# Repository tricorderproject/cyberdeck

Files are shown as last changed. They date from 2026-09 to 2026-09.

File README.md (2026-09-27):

# Open Source Science Tricorder Cyberdeck

Explore alien planets with... the open source science tricorder cyberdeck!

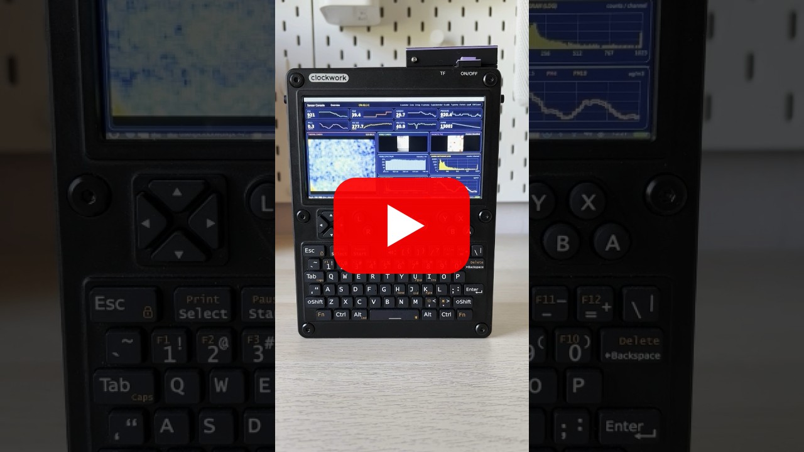
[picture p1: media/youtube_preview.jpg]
Watch the Open Source Science Tricorder Cyberdeck on YouTube


# What is this

This is the Github Repository for the **Open Source Science Tricorder Cyberdeck**, an open-source hardware tricorder-like device similar in function to some of the science tricorder devices from the science fiction series Star Trek.  These devices essentially pack a large number of scientific sensors into small hand-held devices, with the (science fiction) intent being that they would be broadly useful for exploring alien worlds, and making new scientific discoveries.

# Table of Contents

- [What is this](#what-is-this)
- [Pictures](#pictures)
- [Frequently Asked Questions](#frequently-asked-questions)
- [Sensor/Hardware List](#sensorhardware-list)
  - [UConsole](#uconsole)
  - [Main Sensors](#main-sensors)
- [Custom PCBs](#custom-pcbs)
  - [PCB: Hamamatsu Microspectrometer Breakout](#pcb-hamamatsu-microspectrometer-breakout)
  - [PCB: ESP32 Breakout](#pcb-esp32-breakout)
  - [PCB: USB Hub Breakout](#pcb-usb-hub-breakout)
- [3D Printed Components](#3d-printed-components)
  - [3D Print: Main Body](#3d-print-main-body)
  - [3D Print: Back Plate](#3d-print-back-plate)
  - [3D Print: Magnetometer Top and Bottom](#3d-print-magnetometer-top-and-bottom)
  - [3D Print: Power Switch](#3d-print-power-switch)
- [Physical Assembly Video](#physical-assembly-video)
- [Firmware (ESP32)](#firmware-esp32)
- [User Interface (Python/UConsole)](#user-interface-pythonuconsole)
- [Design Philosophy and Iterations](#design-philosophy-and-iterations)
  - [Where it was coming from: The Arducorder Mini](#where-it-was-coming-from-the-arducorder-mini)
  - [Iteration 8: Attaching something to an iPhone](#iteration-8-attaching-something-to-an-iphone)
  - [Iteration 9: Teensycorder: Trying to make something that looked like a BlackBerry](#iteration-9-teensycorder-trying-to-make-something-that-looked-like-a-blackberry)
  - [Iteration 10: T-Deck-Corder](#iteration-10-t-deck-corder)
  - [Iteration 11: Initial Cyberdeck explorations with the BTree](#iteration-11-initial-cyberdeck-explorations-with-the-btree)
  - [Iteration 12: A smaller Cyberdeck with the Clockwork Pi PicoCalc](#iteration-12-a-smaller-cyberdeck-with-the-clockwork-pi-picocalc)
  - [Iteration 13: The Open Source Science Tricoder Cyberdeck](#iteration-13-the-open-source-science-tricoder-cyberdeck)
- [Errata](#errata)
  - [Things that are real errors](#things-that-are-real-errors)
  - [Things that I just don't like, or that aren't implemented yet](#things-that-i-just-dont-like-or-that-arent-implemented-yet)
- [AI Usage](#ai-usage)
- [License](#license)
- [Warranty](#warranty)
- [Contact](#contact)

# Pictures

| Main Screen | Spectrometer Screen | Magnetic imager in use (1) | Magnetic imager in use (2) |
| :---: | :---: | :---: | :---: |
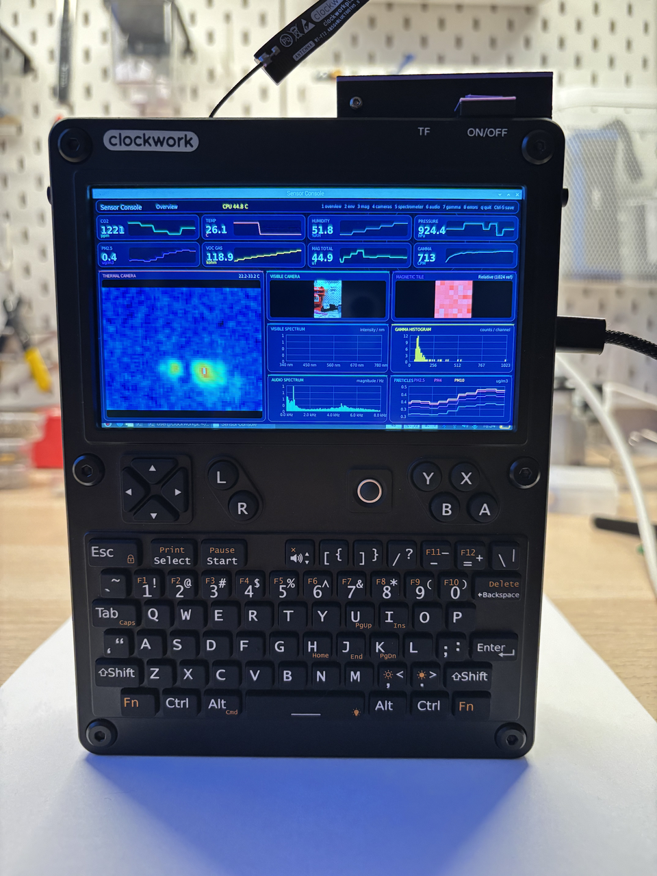
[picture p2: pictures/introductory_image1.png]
Introductory image 1
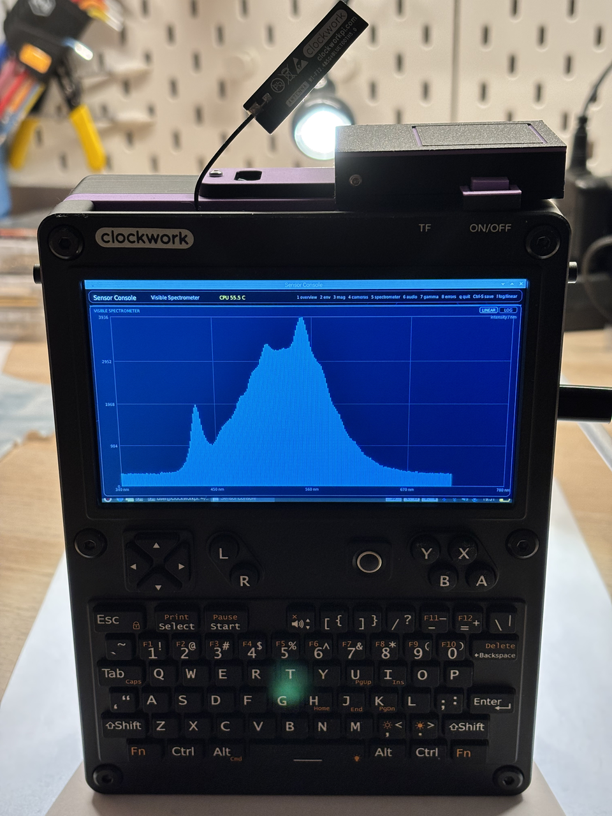
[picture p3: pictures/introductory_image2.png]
Introductory image 2
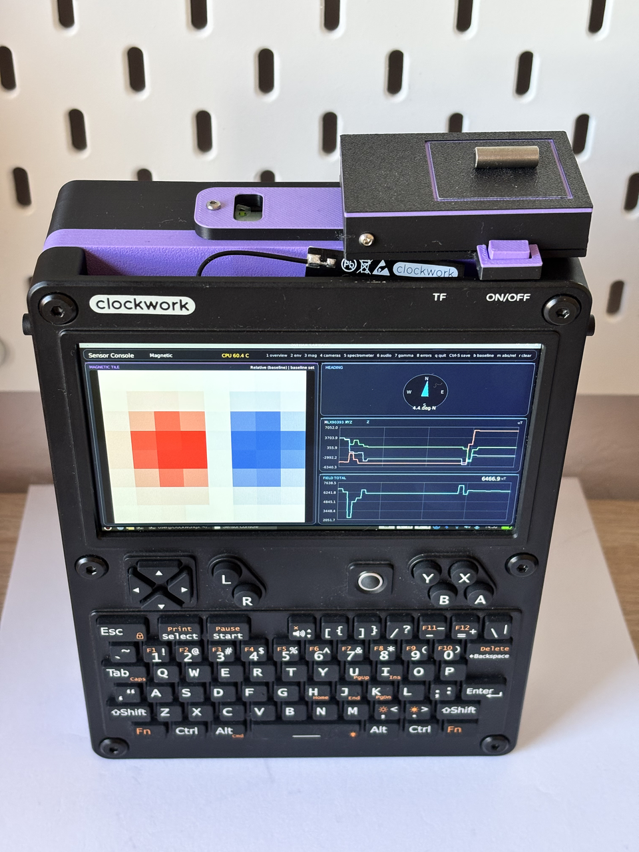
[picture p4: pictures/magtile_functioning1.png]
Magnetic imaging tile in use
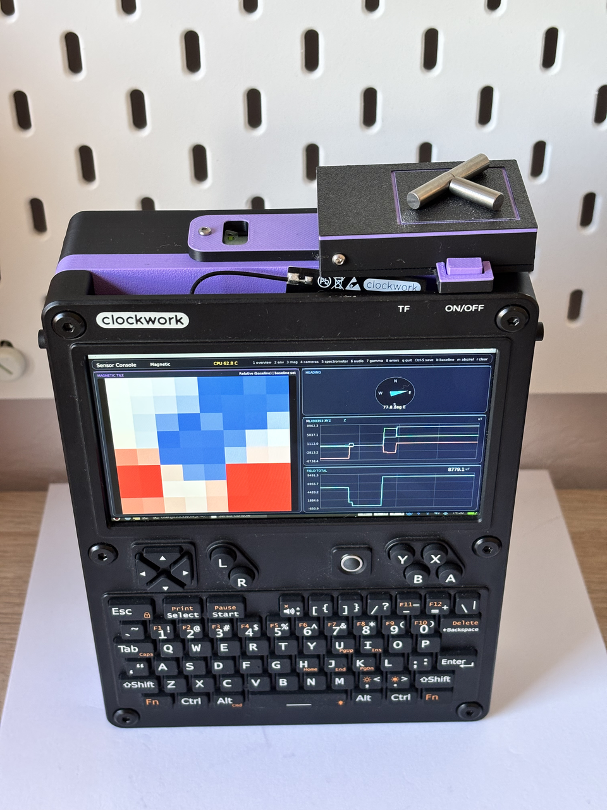
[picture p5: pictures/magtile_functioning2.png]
Magnetic imaging tile in use
|  |  |  |  |
| **Main body with components** | **Main body and back cover** | **Assembled (from back)** | |
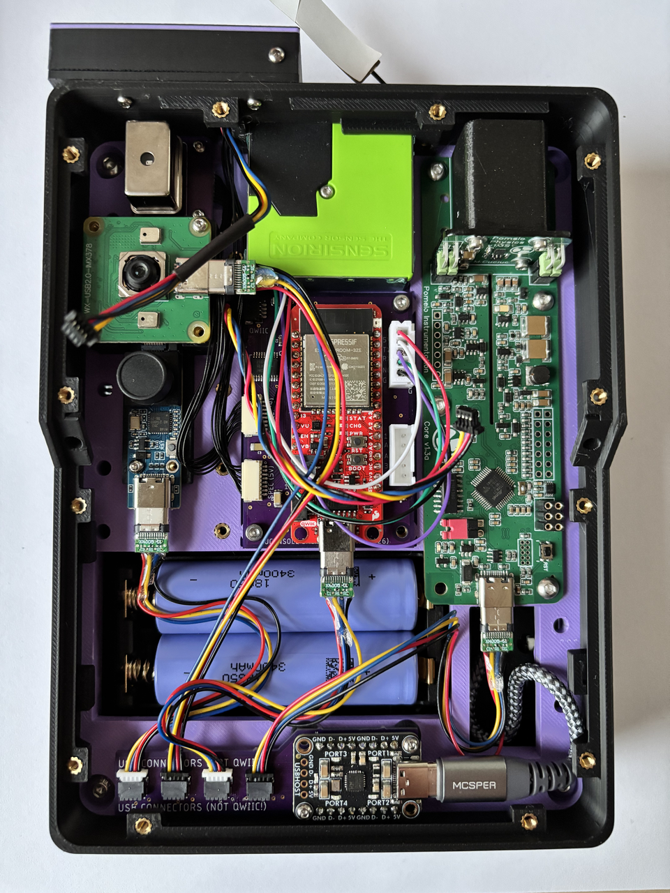
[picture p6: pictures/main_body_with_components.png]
Main body with components installed
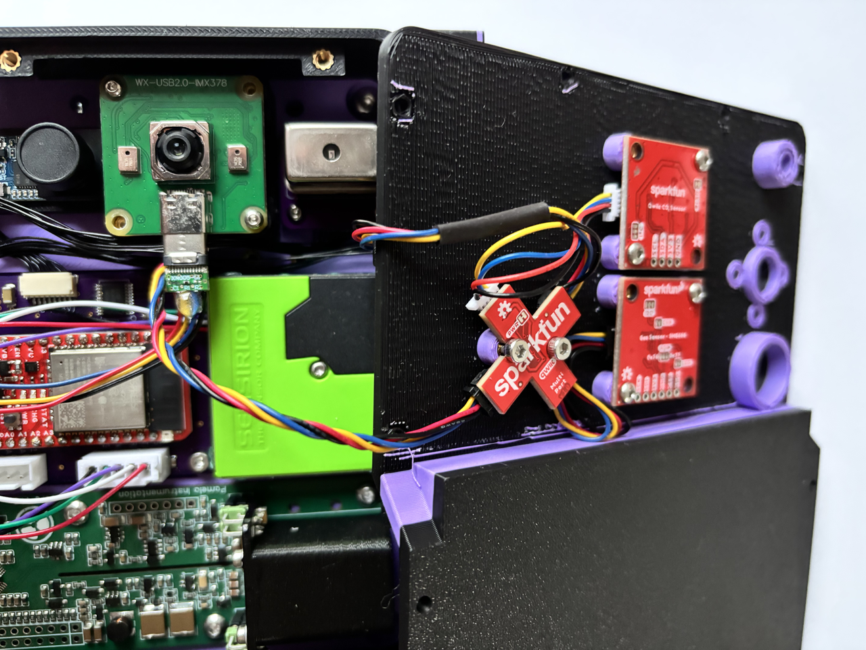
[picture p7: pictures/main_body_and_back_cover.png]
Main body and back cover, opened
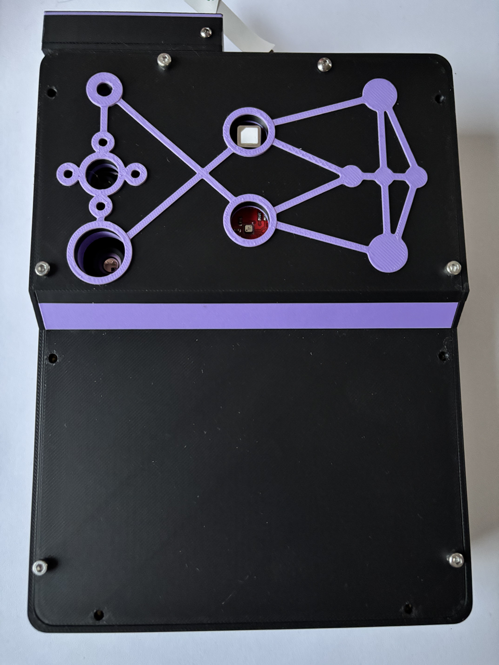
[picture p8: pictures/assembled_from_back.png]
Assembled, viewed from the back
|  |  |  | |

# Frequently Asked Questions

**Q1: What is a tricorder?**

A tricorder is a fictional device from the TV series Star Trek, that characters (like Spock) would take with them when they traveled to alien planets.  The tricorder is essentially like a box full of sensors, that would tell them all sorts of things about the environments they would travel to -- like detecting lifeforms, helping them make discoveries, or solve whatever challenges they faced.  There are nominally two kinds of tricorders in the shows -- medical tricorders (that they use for medical diagnosis), and the science tricorders, which they use for scientific/exploratory tasks. 

**Q2. What can it sense?**

This currently has the following sensing capabilities:
- **Thermal Imaging:** a 80x62 Waveshare imager, paired with a regular visible USB camera
- **Visible Spectroscopy:** a Hamamatsu C12666MA microspectrometer, with 256 spectral channels between 340nm and 780nm (in practice, the spectral resolution is about 15nm)
- **Magnetic Field Imager:** An 8x8 (64 pixel) magnetic field camera, provided by the Sparkfun Magnetic Imaging Tile. In practice this can go up to about 20KHz (i.e. 20,000 frames per second). This is also paired with a regular magnetometer (MLX90393) for magnetic field strength and direction.
- **Radiation Spectroscopy:** Where previous open source science tricorders have included radiation sensors, this version includes the Pomelo radiation spectroscopy detector, which uses a scintillation crystal and can differentiate energy levels.
- **Environmental Sensors:** CO2 level, VOC level, Air particulate matter (e.g. PM1/2.5/4/10), ambient temperature, pressure, and humidity.

**Q3: What is a cyberdeck?**

A cyberdeck is the name for essentially small handheld consoles (that include small screens and keyboards), that frequently run full operating systems, and that are often designed to be hackable/modified.  This build is based on the [UConsole by Clockwork Pi](https://www.clockworkpi.com/home-uconsole), which uses a Raspberry Pi compute module -- so it runs linux, and has several cores, about 4GB of RAM, and lots of eMMC storage. 

**Q4: Are there videos showing it functioning?**

Yes, [here is a video on Youtube](https://youtube.com/shorts/MCvRtOt6pII) showing its main functionality. 

**Q5: Is there a video of it being assembled/the inside?**

Yes!  [Here is a video of the inside being put together](https://youtube.com/shorts/LsJ3JqqFUqU), component by component.

**Q6: What does open source mean in the context of open hardware?**

Open hardware is like open source software, except that it is the designs for the device that are openly shared/distributed.  The software/firmware for the device is also included. 

**Q7: Can I build this?**

The honest answer is -- maybe.  This is a prototype, not a product, and there are lots of rough edges.  Historically, most of the utility from the past releases of the open source science tricorders seems to be educational, inspirational (i.e. a real tricorder-like device!), or derivatives (e.g. folks using part of the designs for their own work).  The devices are quite complex to build, and quite expensive.  

**Q8: Why did you build this?**

I grew up watching Star Trek, and my first career choice was always space explorer -- it just turned out that I was born a little early for that to be a common occupation.  But we're not going to get there just sitting around -- we make the future ourselves, so let's build the technology to become future explorers, and make new discoveries together.

**Q9: Who was this made by?**

The Open Source Science Tricorder Project is an open-source educational outreach by Dr. Peter Jansen, a professor at the University of Arizona.  You can learn more about me [here](https://cognitiveai.org/).

**Q10: How many past open source science tricoders have their been?**

I have made about a dozen designs, but only four (including this cyberdeck) have been official 'releases' with significant documentation, the others are generally iterations or prototypes (and some of the failed prototypes for this cyberdeck design are shown in the section below, since it's always exciting to see the development process!). I used to post a design blog on the process, but I am a little busy these days, and don't have a lot of free time, so it now takes me longer to build these things than I am willing to admit. 

The past major releases are the [Mark 1](https://tricorderproject.org/tricorder-mark1.html) and [Mark2 2](https://tricorderproject.org/tricorder-mark2.html) in 2012, the [Arducorder Mini](https://hackaday.io/project/1395-open-source-science-tricorder) in 2014, and then this Cyberdeck in 2026.  In the interim, I also worked on other educational open source hardware projects, like the open source computed tomography (CT) scanners. 

**Q11: How much did this Cyberdeck cost to build?**

The UConsole itself, CM4 compute module, and associated HackerGadgets extension boards, are likely around $300-$400, while the components and build here are likely around $1000.  The visible microspectrometer and the pomelo radiation spectrometer are by far the most expensive components.

# Sensor/Hardware List

The following is the core hardware used in this device, including links to datasheets/etc.

## UConsole

| Component | Description | Link |
| --- | --- | --- |
| UConsole | Clockwork Pi UConsole | [ClockworkPi](https://www.clockworkpi.com/home-uconsole) |
| UConsole Extension | Internal USB Hub, CM5 adapter, battery board | [Hacker Gadgets](https://hackergadgets.com/products/uconsole-upgrade-kit) |

## Main Sensors

| Component | Description | Link |
| --- | --- | --- |
| Thermal Camera | Waveshare Long-wave IR Camera (80x62, USB C) | [Waveshare](https://www.waveshare.com/thermal-camera.htm?sku=25288) |
| USB Camera | Waveshare IMX378 12MP | [Waveshare](https://www.waveshare.com/imx378-12mp-usb-camera-a.htm) |
| Microspectrometer | Hamamatsu C12666MA | [Hamamatsu](https://www.hamamatsu.com/us/en/product/optical-sensors/spectrometers/mini-spectrometer/C12666MA.html) |
| Radiation Sensor | Pomelo Spectroscopic Radiation Detector | [Crowd Supply](https://www.crowdsupply.com/pomelo-instrumentation/pomelo) |
| Air Particle Sensor | Sensirion Particulate Matter Sensor SPS30 | [Sensirion](https://sensirion.com/products/catalog/SPS30) |
| Magnetic Imaging Tile | SparkFun Magnetic Imaging Tile - 8x8 | [SparkFun](https://www.sparkfun.com/sparkfun-magnetic-imaging-tile-8x8.html) |
| Magnetometer | MLX90393 Breakout | [SparkFun](https://www.sparkfun.com/sparkfun-triple-axis-magnetometer-breakout-mlx90393-qwiic.html) |
| CO2 Sensor | SCD40 CO2/Temp/Humidity Breakout | [SparkFun](https://www.sparkfun.com/sparkfun-co2-humidity-and-temperature-sensor-scd40-qwiic.html) |
| Environmental Sensor | BME680 Temp/Pressure/Humidity/VOC | [SparkFun](https://www.sparkfun.com/sparkfun-environmental-sensor-breakout-bme680-qwiic.html) |
| QWIIC Hub | SparkFun Qwiic MultiPort | [SparkFun](https://www.sparkfun.com/sparkfun-qwiic-multiport.html) |

In addition to the hardware above, a handful of custom PCBs are used (described below).

# Custom PCBs

While effort was made to try and have everything in the device be off-the-shelf for this build, a handful of boards were used to make things a little more compact. 

## PCB: Hamamatsu Microspectrometer Breakout

This is a small breakout for the Hamamatsu CD12666MA microspectrometer, that primarily provides a low-profile connector, an op-amp buffer, and handful of filtering passives to help keep the power clean. 

| Board (front) | Board (back) | PCB (top) | PCB (bottom) |
| :---: | :---: | :---: | :---: |
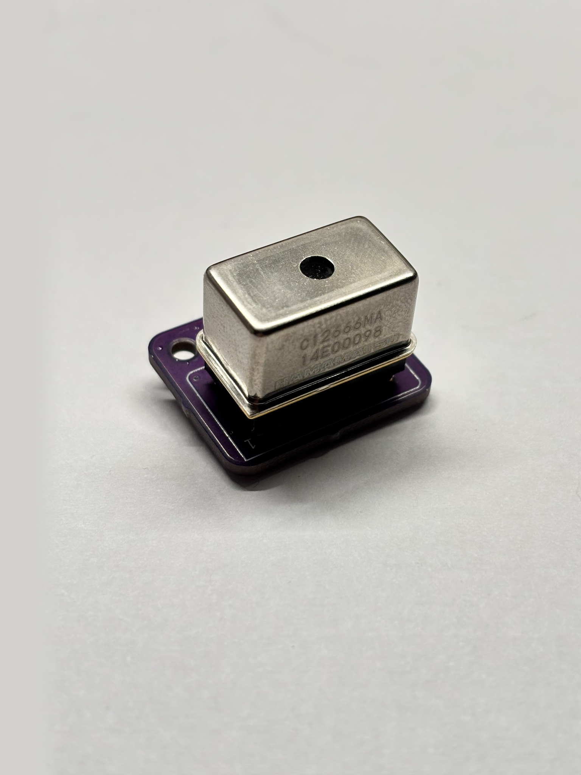
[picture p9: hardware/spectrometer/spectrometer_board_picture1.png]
Spectrometer breakout, front
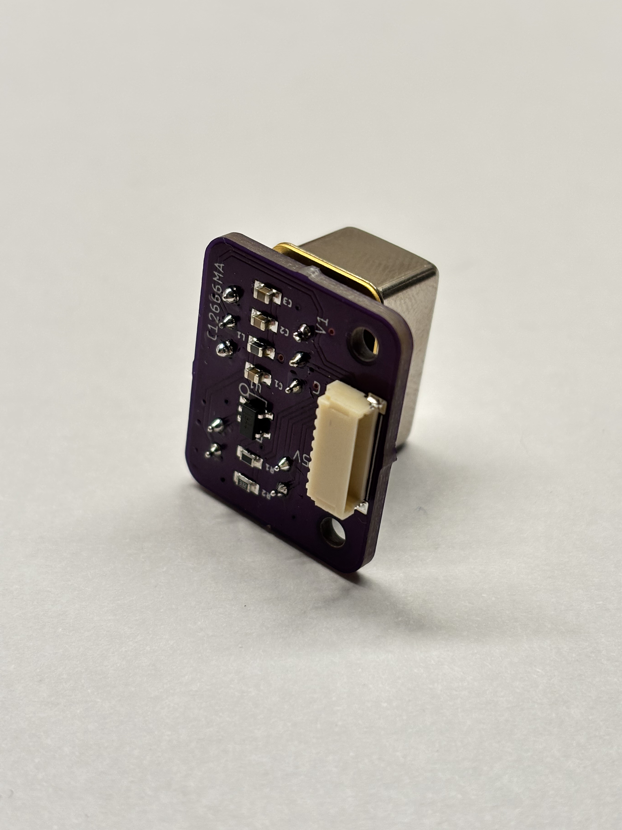
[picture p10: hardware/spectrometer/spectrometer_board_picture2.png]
Spectrometer breakout, back
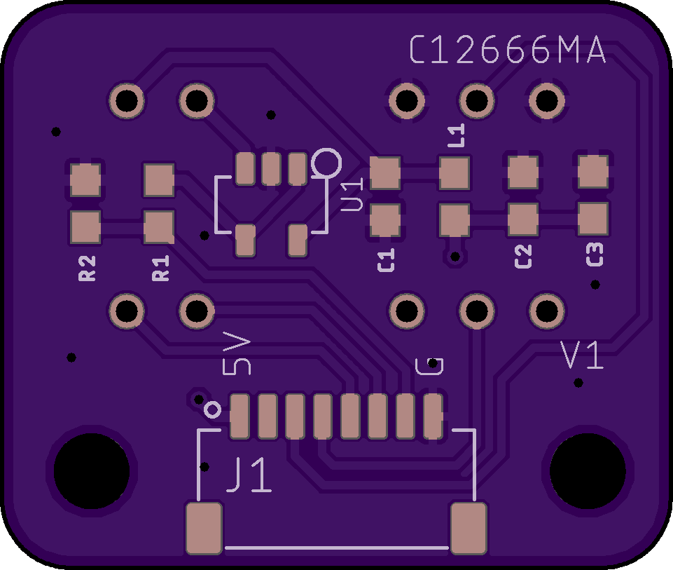
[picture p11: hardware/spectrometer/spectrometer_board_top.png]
Spectrometer breakout PCB render, top
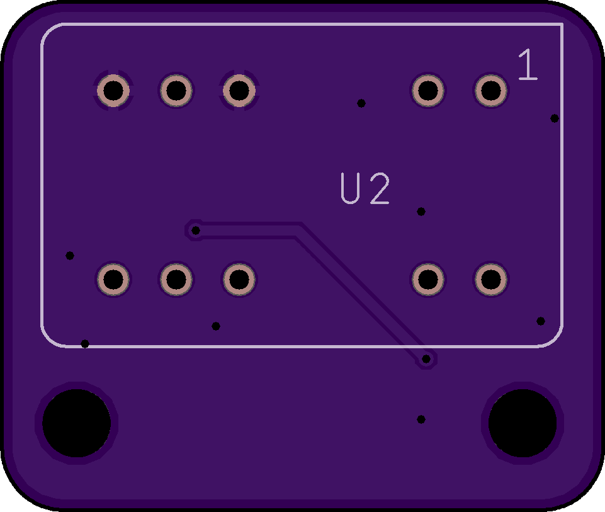
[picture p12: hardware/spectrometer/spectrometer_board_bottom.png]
Spectrometer breakout PCB render, bottom
|  |  |  |  |
| **Reflow (toaster oven)** | | | |
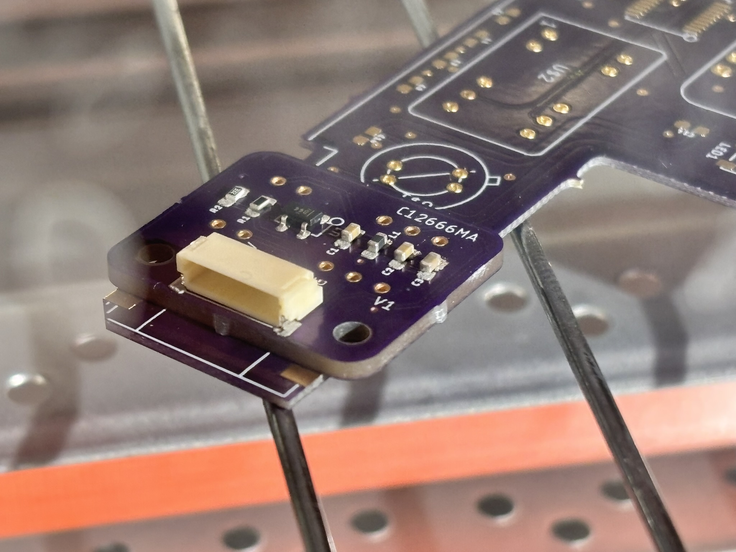
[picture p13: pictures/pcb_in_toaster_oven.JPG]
Spectrometer breakout PCB being reflowed in a toaster oven
|  | | | |

**Design files (EAGLE 9.6.2):** [Schematic (PDF)](hardware/spectrometer/spectrometer-breakout-1c2.pdf) &middot; [Schematic (.sch)](hardware/spectrometer/spectrometer-breakout-1c2.sch) &middot; [Board (.brd)](hardware/spectrometer/spectrometer-breakout-1c2.brd) &middot; [Parts list](hardware/spectrometer/spectrometer-breakout-1b2-partslist.txt)

## PCB: ESP32 Breakout

This is an ESP32 breakout that provides a handy connection between the UConsole (over USB) to most of the other (non-USB) sensors.  The ESP32 board itself is the [Sparkfun ESP32-WROOM USB C](https://www.sparkfun.com/sparkfun-thing-plus-esp32-wroom-usb-c.html). On the left there are small-form connectors for the spectrometer, magnetic imaging tile, and a QWIIC I2C connector.  On the right side are two standard 0.1-spaced headers, one for communicating with the SPS30 air particle sensor, and the other is open, and is intended for a light source for the visible spectrometer. 

| Board | PCB (top) | PCB (bottom) |
| :---: | :---: | :---: |
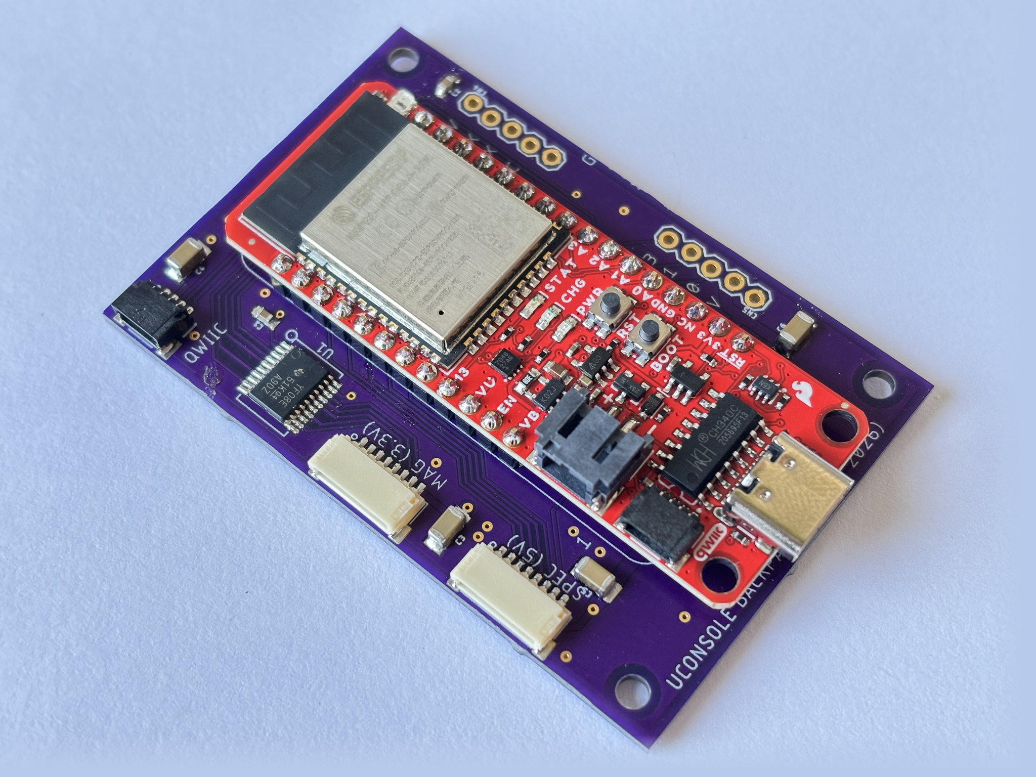
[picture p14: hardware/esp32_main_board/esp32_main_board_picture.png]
ESP32 breakout board
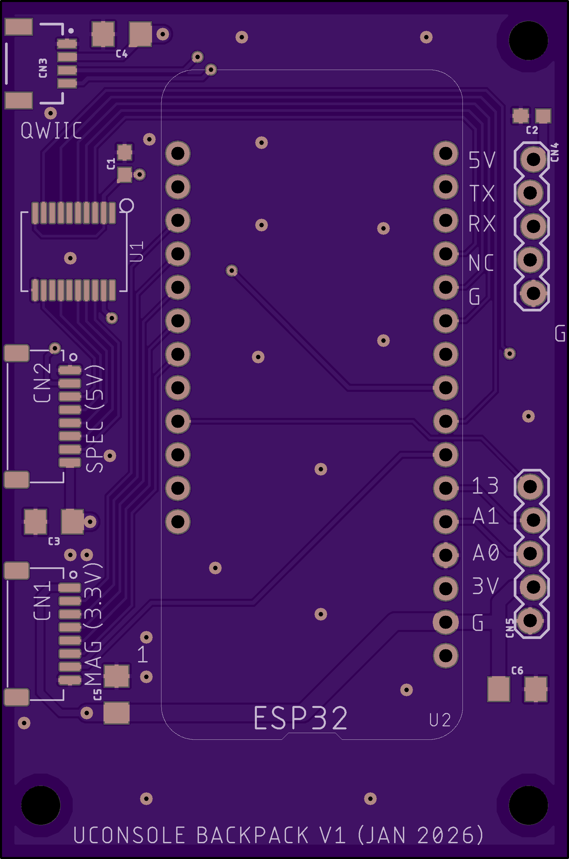
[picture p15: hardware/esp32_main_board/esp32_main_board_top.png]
ESP32 breakout PCB render, top
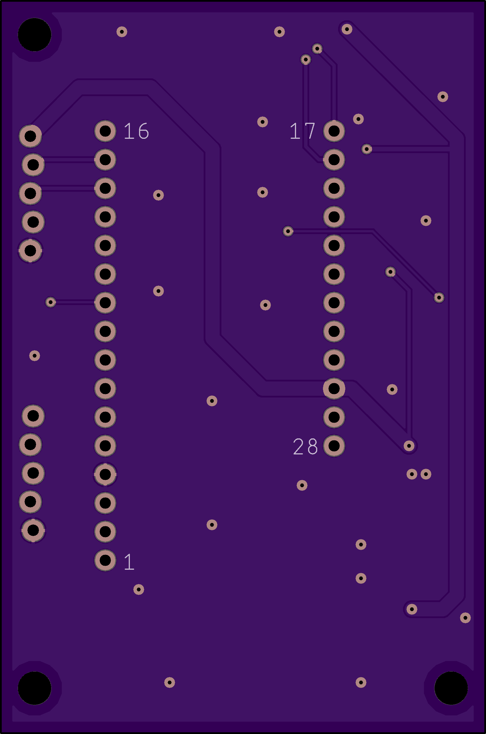
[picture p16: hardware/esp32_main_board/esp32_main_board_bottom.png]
ESP32 breakout PCB render, bottom
|  |  |  |

**Design files (EAGLE 9.6.2):** [Schematic (PDF)](hardware/esp32_main_board/clockwork-backpack-1a5.pdf) &middot; [Schematic (.sch)](hardware/esp32_main_board/clockwork-backpack-1a5.sch) &middot; [Board (.brd)](hardware/esp32_main_board/clockwork-backpack-1a5.brd) &middot; [Parts list](hardware/esp32_main_board/clockwork-backpack-1a5-partslist.txt)

## PCB: USB Hub Breakout

This is a breakout for a low-profile USB hub. USB connectors are enormous, and so this further breaks out the [Adafruit CH334F Mini 4-Port USB Hub breakout](https://www.adafruit.com/product/5997) to small JST connectors.  These, unfortunately, are the same JST connectors used by the QWIIC system, which is not a good design decision, so you need to be careful that you're not connecting QWIIC connectors to these 5V usb connections. 

| Board | PCB (top) | PCB (bottom) |
| :---: | :---: | :---: |
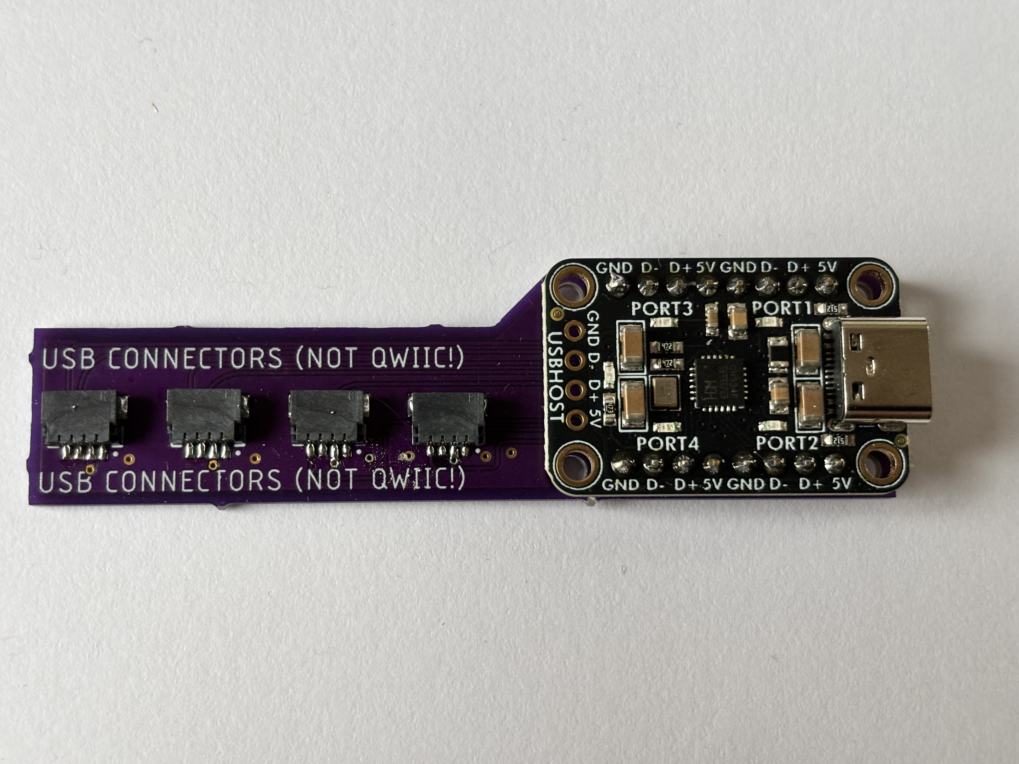
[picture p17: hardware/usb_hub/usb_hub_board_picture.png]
USB hub breakout board
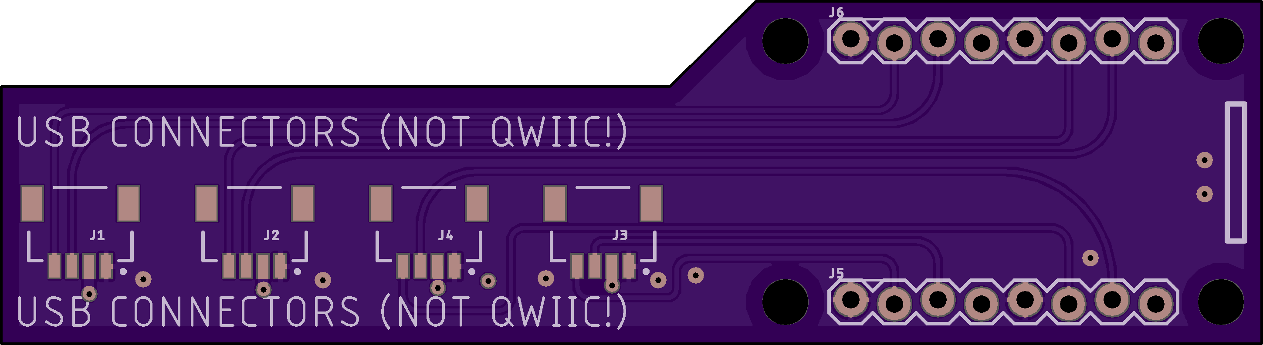
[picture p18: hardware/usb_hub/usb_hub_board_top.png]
USB hub breakout PCB render, top
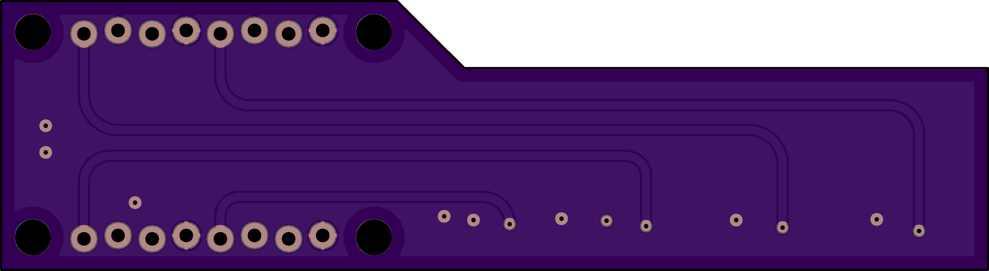
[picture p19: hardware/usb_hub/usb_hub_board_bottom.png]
USB hub breakout PCB render, bottom
|  |  |  |

**Design files (EAGLE 9.6.2):** [Schematic (PDF)](hardware/usb_hub/usb-hub-1b.pdf) &middot; [Schematic (.sch)](hardware/usb_hub/usb-hub-1b.sch) &middot; [Board (.brd)](hardware/usb_hub/usb-hub-1b.brd)

# 3D Printed Components

The enclosure and sensor mounts are 3D printed. The models are authored in OpenSCAD, and both the source and exported STLs are included below.

## 3D Print: Main Body

This is the main physical component, where nearly all of the sensors mount to. It replaces the back of the uConsole, and screws to the uConsole using four M4 screws at the four corners.  Brass inserts, primarily M2.5 (but a few M2 and M3) are used to allow other components to mount to this print.

| Model | With inserts | With components |
| :---: | :---: | :---: |
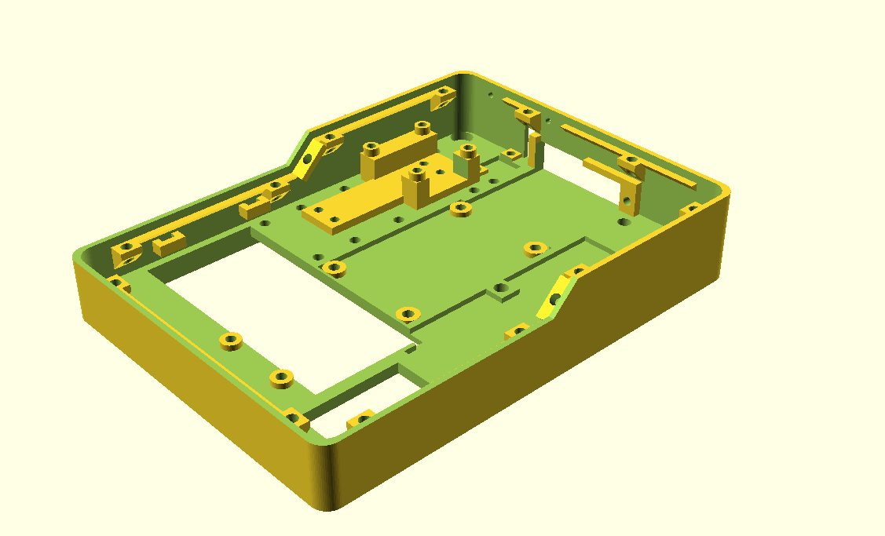
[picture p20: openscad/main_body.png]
Main body model render
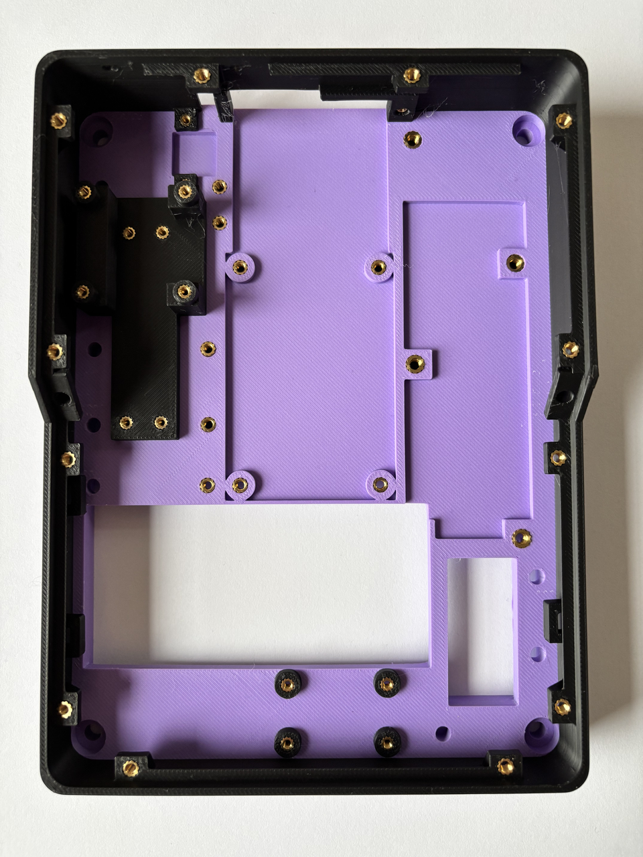
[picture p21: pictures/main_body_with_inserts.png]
Main body with heat-set inserts
|  |  | <a href="pictures/main_body_with_components.png">Main body with components installed</a> |

**Design files (OpenSCAD):** [Model (.stl)](openscad/main_body.stl) &middot; [Source (.scad)](openscad/osst_cyberdeck_sept2026.scad)

## 3D Print: Back Plate

The back plate mounts onto the main body, and also allows a handful of environmental sensors to be mounted. These use the Sparkfun breakout mounting pattern (which is nominally about 25x25mm). It also contains the Sparkfun QWIIC hub, which provides additional QWIIC connectors for the ESP32 breakout. 

| Model | With inserts | With components (1) | With components (2) |
| :---: | :---: | :---: | :---: |
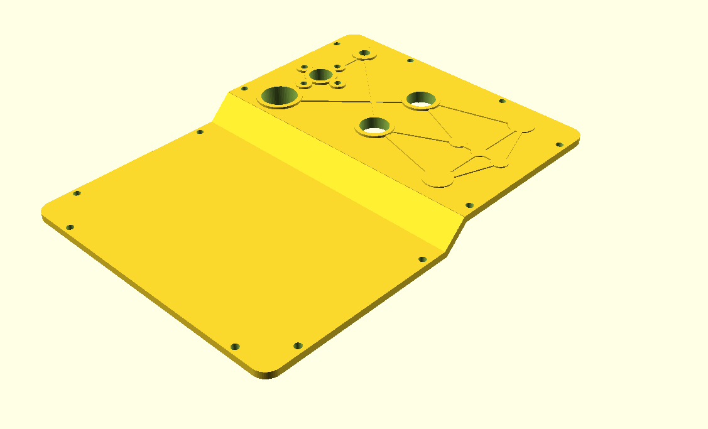
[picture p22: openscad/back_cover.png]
Back plate model render
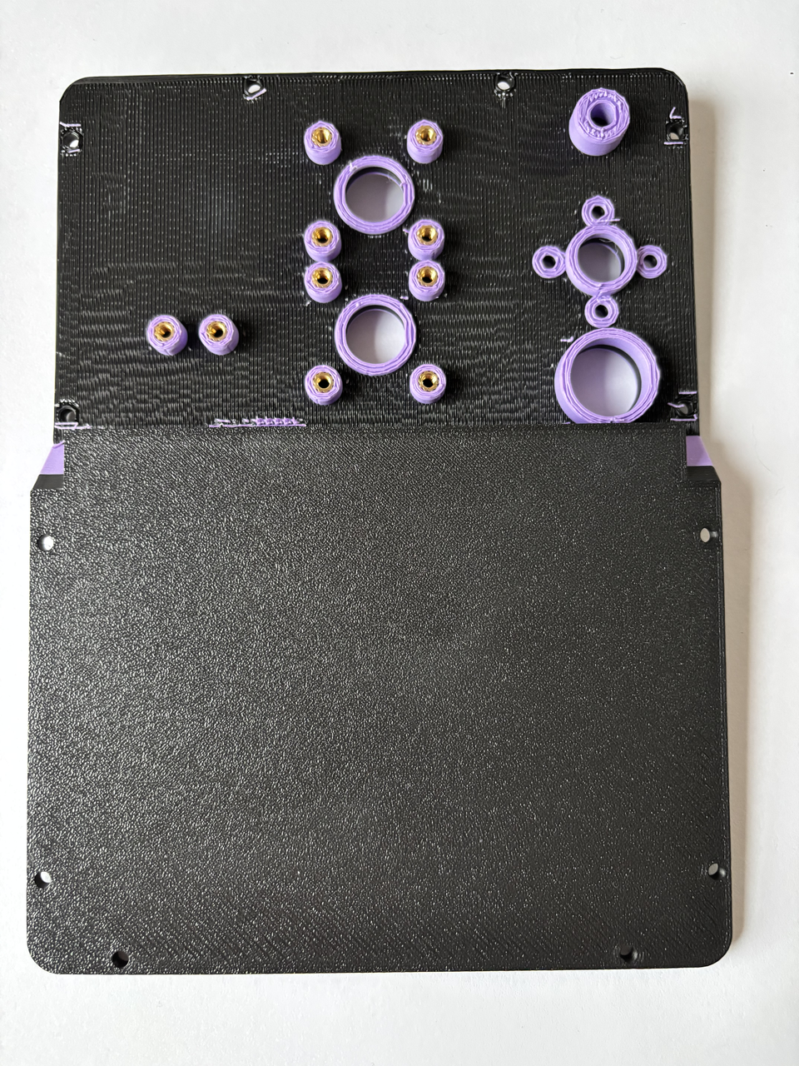
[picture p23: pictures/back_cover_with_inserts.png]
Back plate with heat-set inserts
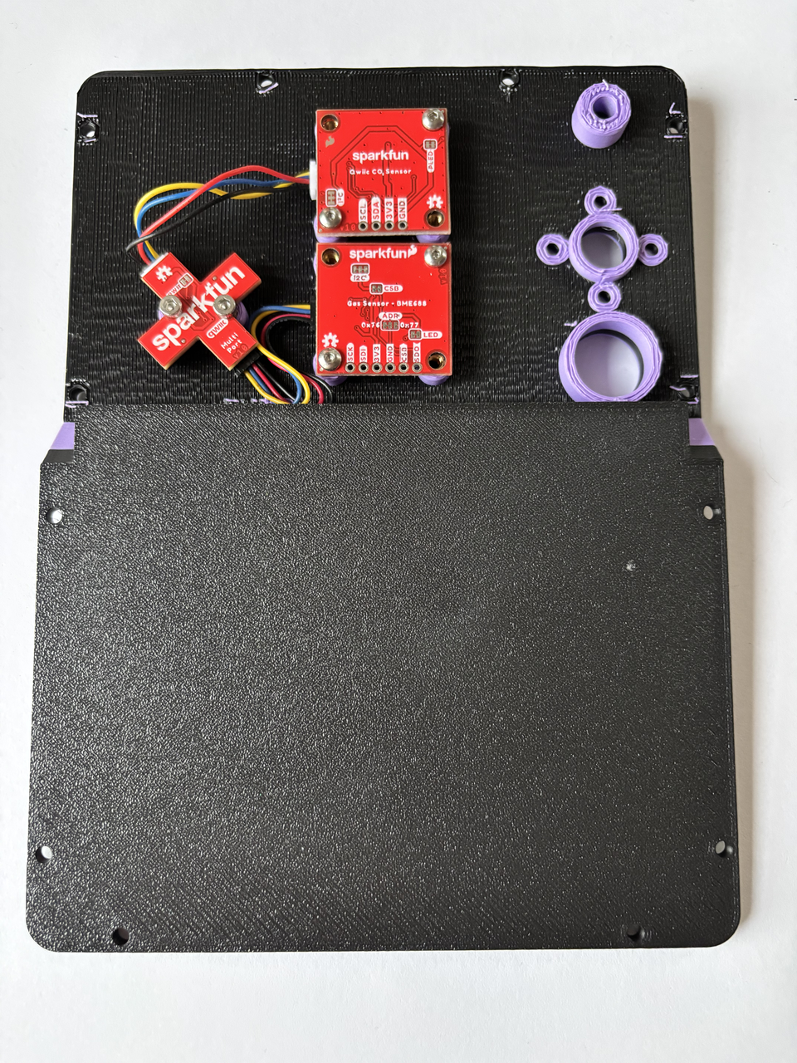
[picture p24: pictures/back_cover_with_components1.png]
Back plate with components installed
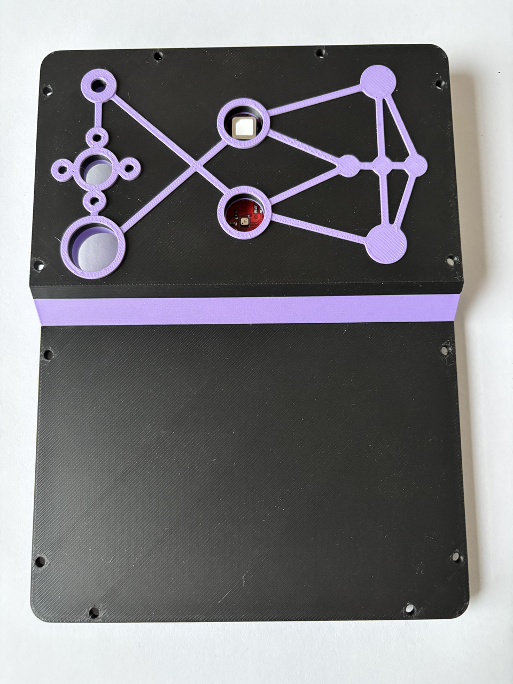
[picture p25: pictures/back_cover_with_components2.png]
Back plate with components installed
|  |  |  |  |

**Design files (OpenSCAD):** [Model (.stl)](openscad/back_cover.stl) &middot; [Source (.scad)](openscad/osst_cyberdeck_sept2026.scad)

## 3D Print: Magnetometer Top and Bottom

This is a (mostly) clamshell design that encloses the magnetic imaging tile, and the magnetometer breakout board.  A handful of brass inserts are used to keep the two sides of the clamshell together. A (very technical) piece of folded paper is used to prevent the magnetometer and magnetic imaging tile boards from short circuiting each other.  The bottom of this piece also includes a hidden duct, that allows the exhaust from the SPS30 air particle sensor to leave the sensor at a right angle, away from the inlet.

| Model (front) | Model (back) | Step 1 | Step 2 |
| :---: | :---: | :---: | :---: |
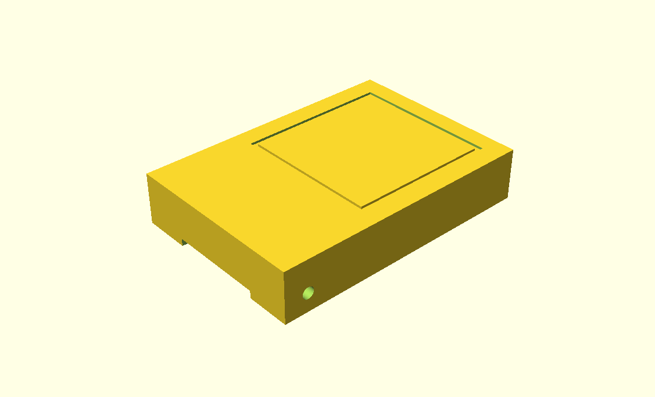
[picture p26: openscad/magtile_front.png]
Magnetometer front model render
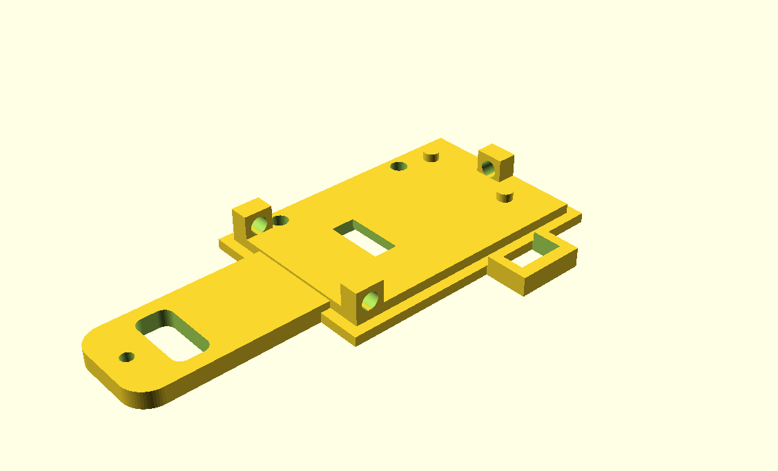
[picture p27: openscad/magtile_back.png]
Magnetometer back model render
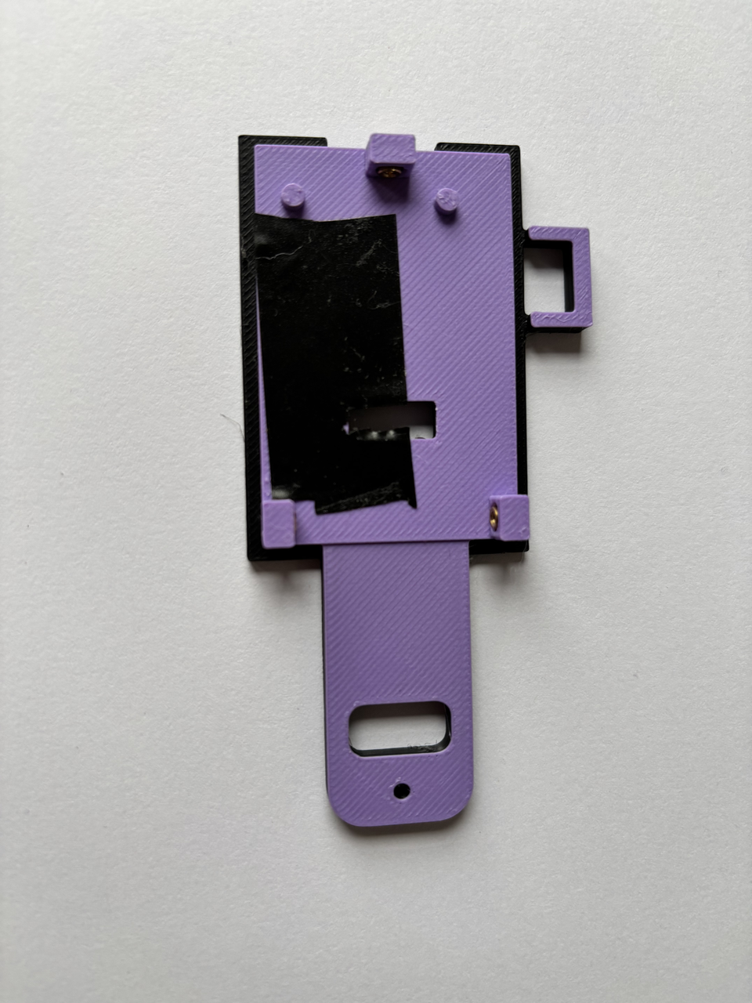
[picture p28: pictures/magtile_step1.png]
Magnetometer assembly step 1
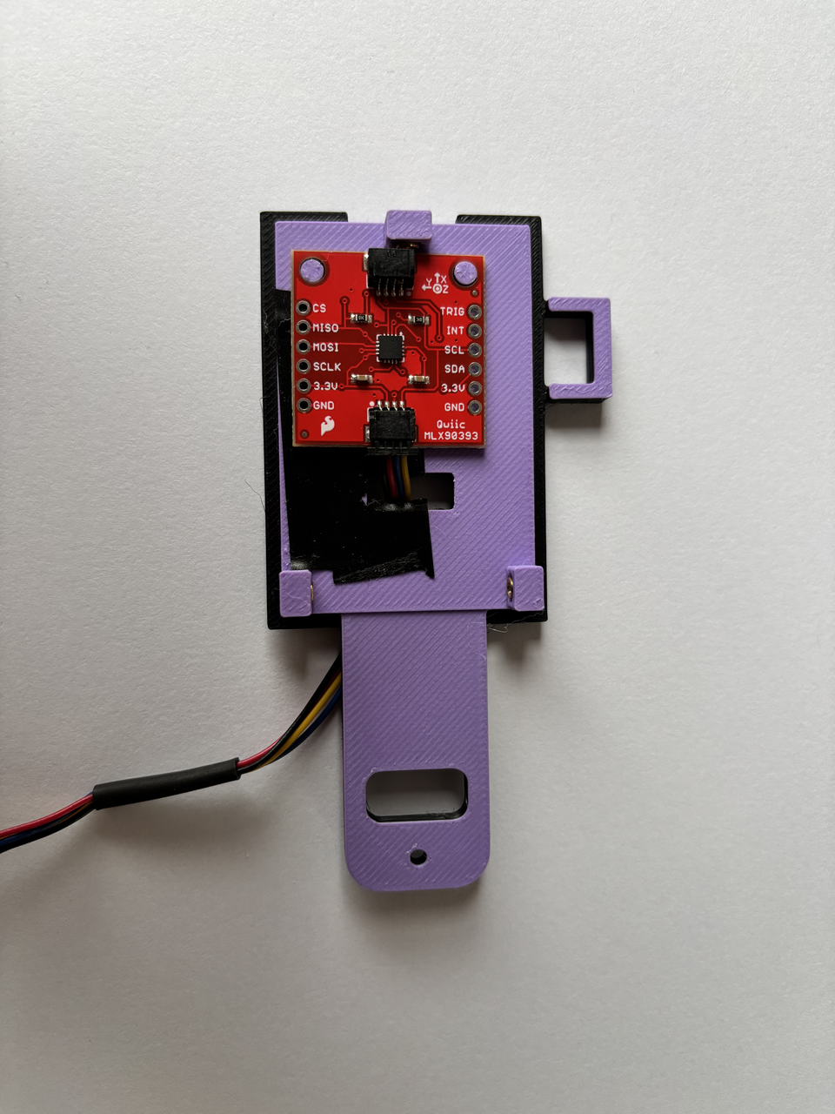
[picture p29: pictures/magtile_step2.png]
Magnetometer assembly step 2
|  |  |  |  |
| **Step 3** | **Step 4** | **Step 5** | **Step 6** |
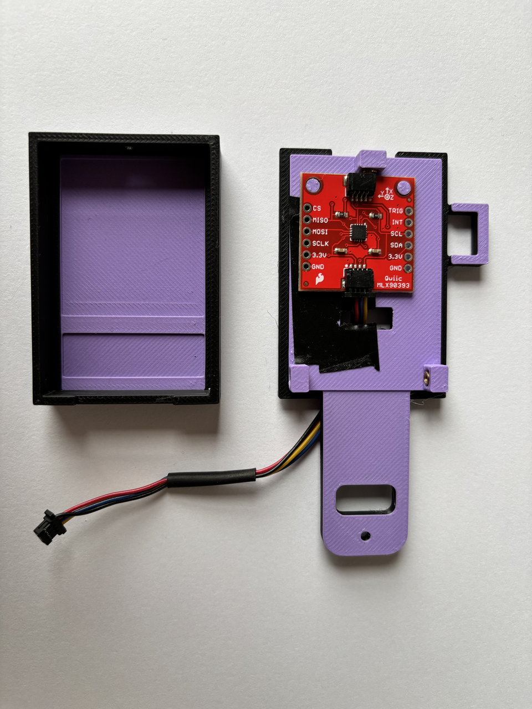
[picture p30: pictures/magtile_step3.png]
Magnetometer assembly step 3
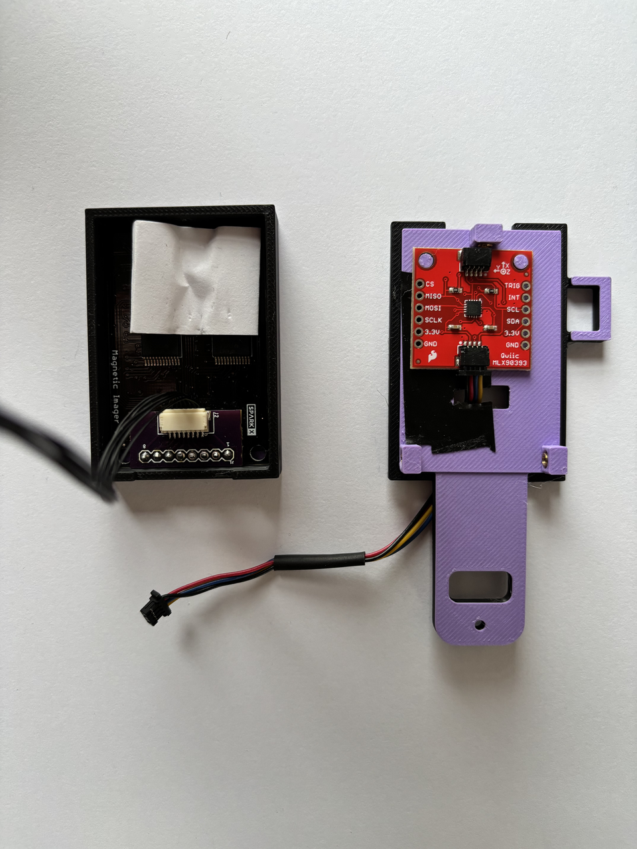
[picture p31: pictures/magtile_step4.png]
Magnetometer assembly step 4
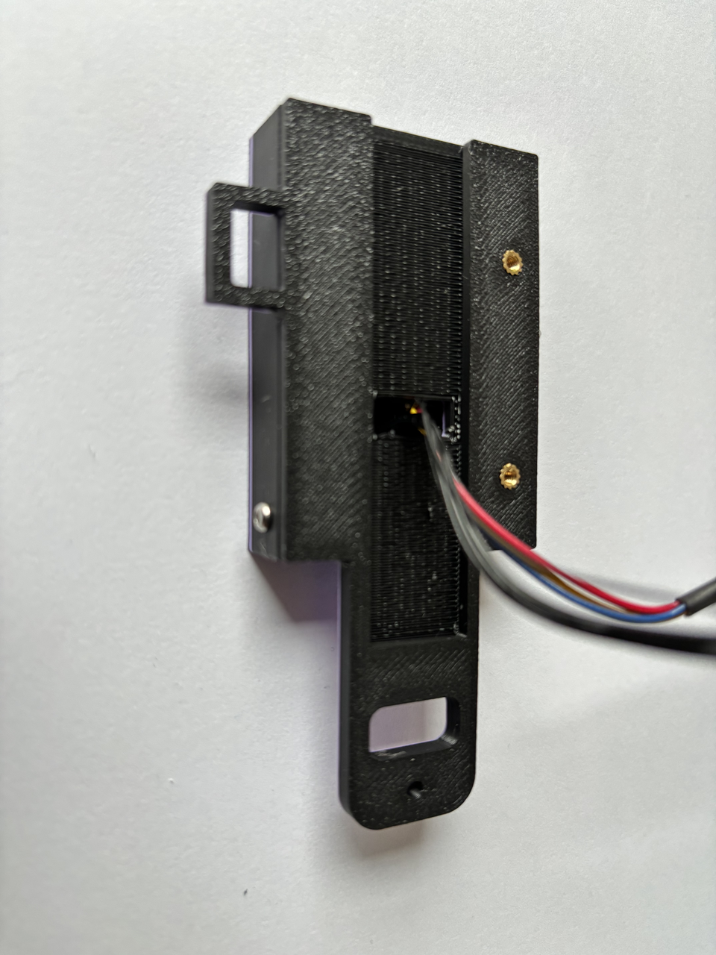
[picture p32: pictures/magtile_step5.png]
Magnetometer assembly step 5
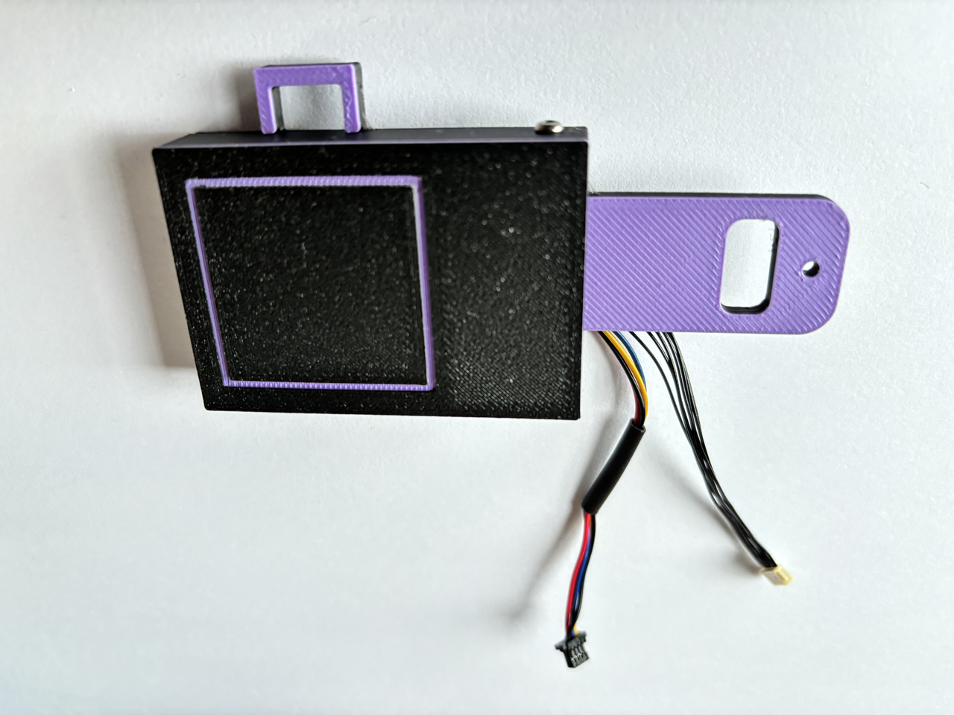
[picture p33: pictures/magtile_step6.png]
Magnetometer assembly step 6
|  |  |  |  |
| **Step 7** | **Example Function** | | |
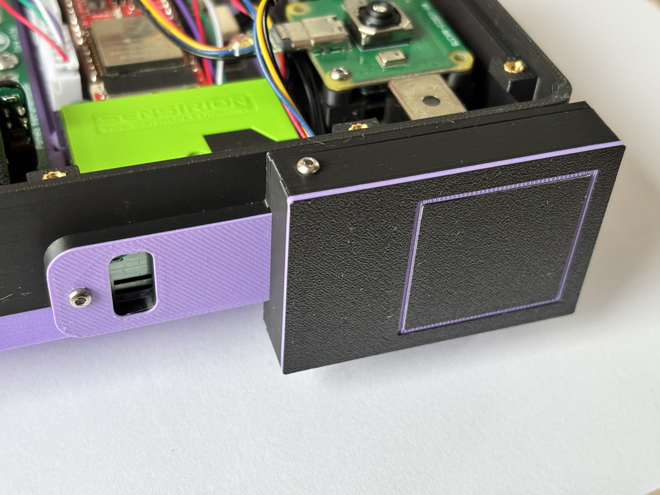
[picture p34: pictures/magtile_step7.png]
Magnetometer assembly step 7
|  | <a href="pictures/magtile_functioning1.png">Magnetometer tile functioning example</a> | | |

**Design files (OpenSCAD):** [Model, front (.stl)](openscad/magtile_front.stl) &middot; [Model, back (.stl)](openscad/magtile_back.stl) &middot; [Source (.scad)](openscad/osst_cyberdeck_sept2026.scad)

## 3D Print: Power Switch

The uConsole has a somewhat hidden power switch, that becomes partically covered by the magnetometer/magnetic imaging tile print above.  This very handy print sits inside the side loop of the magnetic imaging tile print, and when you press it, it presses the real power button. 

| Model | Step 1 | Step 2 |
| :---: | :---: | :---: |
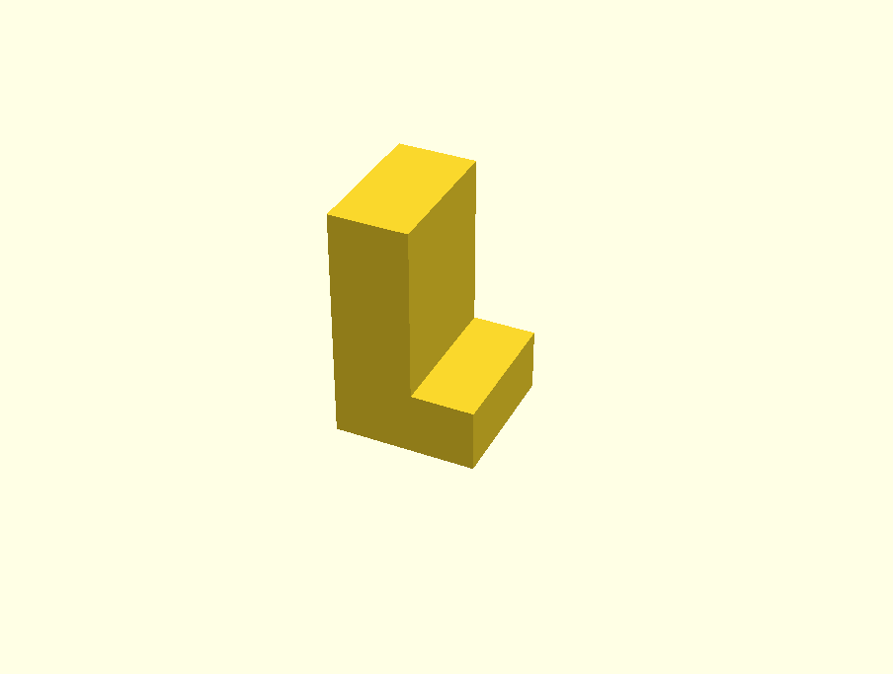
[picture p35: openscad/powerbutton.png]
Power switch model render
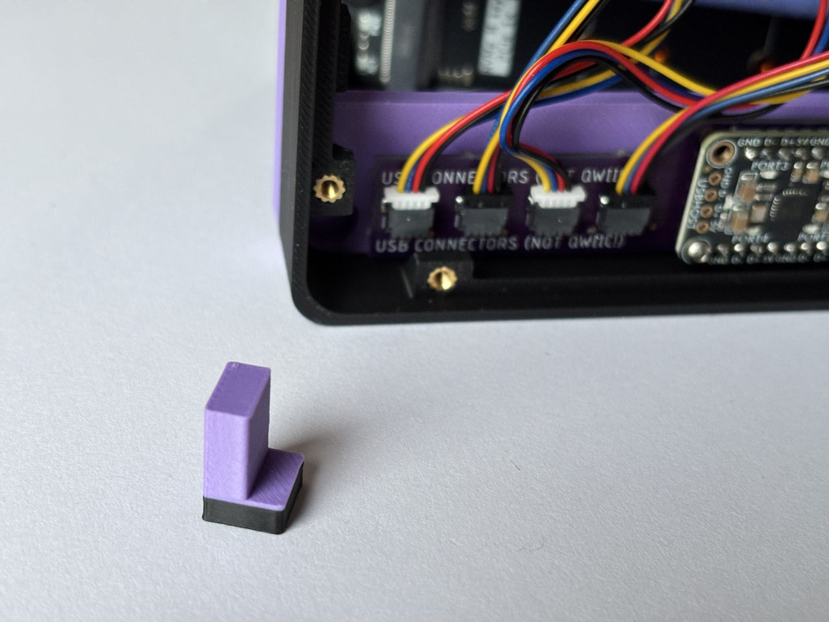
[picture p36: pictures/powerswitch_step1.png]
Power switch assembly step 1
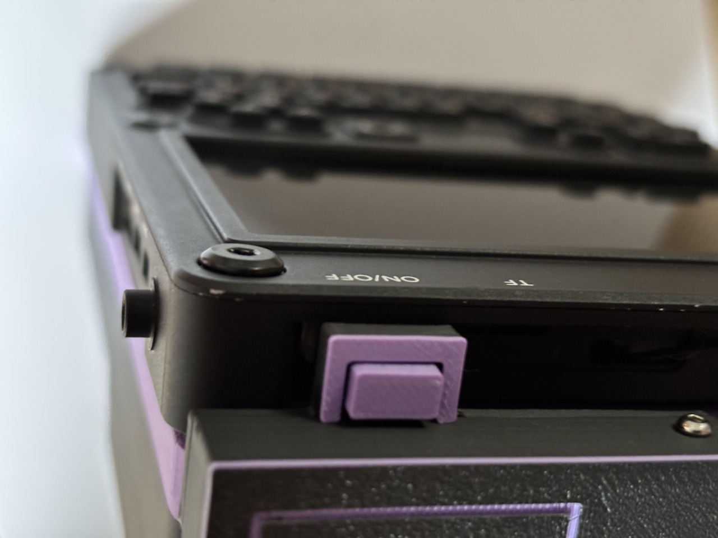
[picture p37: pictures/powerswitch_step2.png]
Power switch assembly step 2
|  |  |  |

**Design files (OpenSCAD):** [Model (.stl)](openscad/powerbutton.stl) &middot; [Source (.scad)](openscad/powerbutton.scad)

# Physical Assembly Video

There's a lot of components in this device, and this short video of stills shows how most of them fit together. 

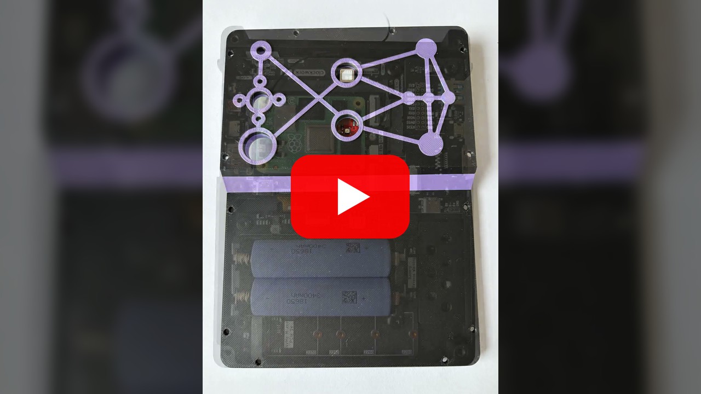
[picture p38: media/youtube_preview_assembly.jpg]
Watch the assembly video on YouTube


# Firmware (ESP32)

The ESP32 firmware essentially periodically polls the various sensors (that are not themselves USB sensors), and then sends the measurements from those sensors down a USB-to-Serial connection to the uConsole.  The packets themselves are in `JSONL` format, like below, so they're very easy for whatever software you have on the uConsole to parse them.  For example:

```
{"sensor":"scd4x","payload":{"atmospheric":{"co2_ppm":612,"temp_c":23.4,"humidity_rh_pct":41.2},"timestamp":184532,"error_state":0}}
{"sensor":"mlx90393","payload":{"magnetic":{"x_ut":12.85,"y_ut":-31.42,"z_ut":45.10},"timestamp":184611,"error_state":0}}
{"sensor":"sps30","payload":{"mass":{"PM1_0":2.113,"PM2_5":2.472,"PM4_0":2.601,"PM10":2.665},"number":{"PM0_5":14.201,"PM1_0":16.744,"PM2_5":16.920,"PM4_0":16.951,"PM10":16.963},"timestamp":184702,"error_state":0}}
{"sensor":"magnetic_tile","payload":{"frame":[[2011,2015,...],[2009,2012,...],...],"timestamp":184730,"error_state":0}}
```

Each line is one packet: a `sensor` name, and a `payload` containing that sensor's readings, a `timestamp` (milliseconds since the ESP32 booted), and an `error_state` (0 = OK). The same format is used for the spectrometer (`spec_cd12666ma`, a 256-channel `spectrum` array), the BME688 environmental sensor (`bme688`), and a one-off `firmware` packet sent at boot with the firmware version and build time.

The ESP32 firmware is in: [esp32/uconsole_sensor_backpack_1b/uconsole_sensor_backpack_1b.ino](esp32/uconsole_sensor_backpack_1b/uconsole_sensor_backpack_1b.ino) (an Arduino sketch, with the per-sensor drivers in the same folder).

# User Interface (Python/UConsole)

The user interface on the uConsole polls the various sensors, and displays their readings in a simple user interface.  The user currently selects which screen they'd like to view using the number keys (1-7), and some of the screens have additional functionality, like allowing the user to take baseline measurements (as in for the magnetic imaging tile). 

The interface itself is written in Python, using `pygame` for rendering.

The user interface main entrypoint is here: [src/UserInterfacePygame.py](src/UserInterfacePygame.py) (see [runme.sh](runme.sh), which launches it).

# Design Philosophy and Iterations 

The design philosophy I wanted to explore with this series of iterations of the *open source science tricorder* project was to make the designs easier for others to replicate, nominally by minimizing reliance on custom printed circuit boards and other complex manufacturing processes.  Because most of the complexity comes from displays, input, and so forth, I ended up exploring this in the context of using other devices to supply the input/output, while trying to "bolt" sensors onto them.  In the end, I'm not entirely sure I met the goal -- and the device is much larger than it needs to be, because of all the space required to have all the sensors be off-the-shelf -- but ultimately, I'm pretty happy with it. 

What you mostly see is the end design, but this took **many** iterations over quite a few years to get to where it is.  Here is a sneak peak at some of those design iterations. 

## Where it was coming from: The Arducorder Mini

The Arducorder mini is a beautifully designed but entirely custom device, described here: [Arducorder Mini build logs](https://hackaday.io/project/1395-open-source-science-tricorder)

| Arducorder Mini (1) | Arducorder Mini (2) | Arducorder Mini (3) | Arducorder Mini (4) |
| :---: | :---: | :---: | :---: |
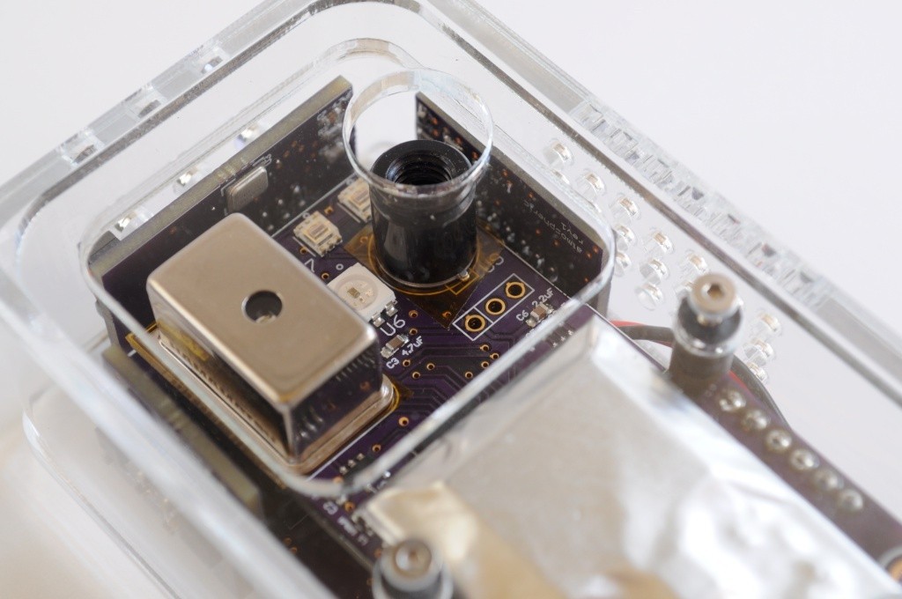
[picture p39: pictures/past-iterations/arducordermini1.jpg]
Arducorder Mini, picture 1
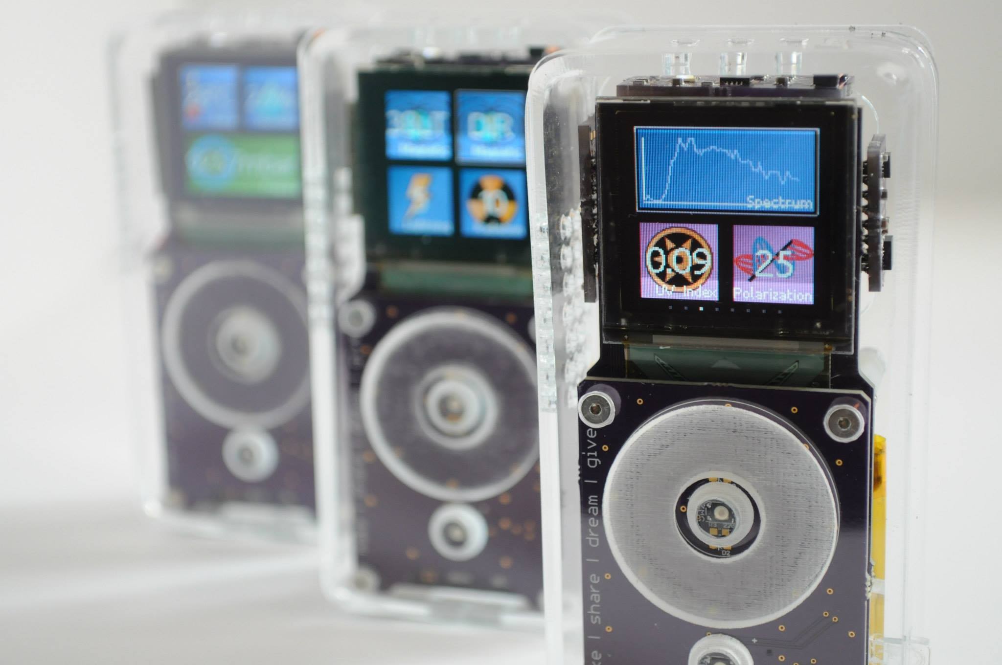
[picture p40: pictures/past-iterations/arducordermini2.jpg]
Arducorder Mini, picture 2
|  |  | <a href="pictures/past-iterations/arducordermini3.jpg">Arducorder Mini, picture 3</a> | <a href="pictures/past-iterations/arducordermini4.jpg">Arducorder Mini, picture 4</a> |

## Iteration 8: Attaching something to an iPhone

My first exploration was building something that would attach to the back of (my) iPhone, using a Raspberry Pi Zero W (running a webserver) to communicate with the iPhone over Wifi, and an Arduino Mini to communicate with all the sensors.  This one ended up about 90% built, but it just seemed like a giant kludge, and I discarded it before making an enclosure.

While the whole device didn't end up working out, one of the outcomes of this iteration was the development of a successful magnetic imaging tile, which ended up being used in future iterations.

The build logs of Iteration 8 are available [here on hackaday.io](https://hackaday.io/project/18518-iteration-8/log/164805-a-new-motherboard-design-now-with-more-pi), with the broader project available [here](https://hackaday.io/project/18518-iteration-8).

| Iteration 8 Prototype | Atmospheric Sensor Prototype | Magnetic Imaging Tile Prototype |
| :---: | :---: | :---: |
| <a href="pictures/past-iterations/iteration8-1.jpeg">Iteration 8, picture 1</a> | <a href="pictures/past-iterations/iteration8-2.jpg">Iteration 8, picture 2</a> | <a href="pictures/past-iterations/iteration8-3.jpg">Iteration 8, picture 3</a> |

## Iteration 9: Teensycorder: Trying to make something that looked like a BlackBerry

Then, I abandoned some of my design principles (as one sometimes does) and decided to try and make something that just used a display and keyboard that was already broken out.  

A post on the Teensycorder is available here: [build log on hackaday.io](https://hackaday.io/project/18518-iteration-8/log/213613-back-at-it-with-the-teensycorder)

| Teensycorder (1) | Teensycorder (2) | Teensycorder (3) | Teensycorder (4) |
| :---: | :---: | :---: | :---: |
| <a href="pictures/past-iterations/teensycorder0.jpeg">Teensycorder, picture 1</a> | <a href="pictures/past-iterations/teensycorder1.jpeg">Teensycorder, picture 2</a> | <a href="pictures/past-iterations/teensycorder2.jpeg">Teensycorder, picture 3</a> | <a href="pictures/past-iterations/teensycorder3.jpeg">Teensycorder, picture 4</a> |
| **Teensycorder (5)** |  |  |  |
| <a href="pictures/past-iterations/teensycorder4.jpeg">Teensycorder, picture 5</a> |  |  |  |

## Iteration 10: T-Deck-Corder

I liked the *idea* of the teensycorder, but I didn't really like how big it was turning out.  Around the same time, the [T-Deck (a small blackberry-like device)](https://lilygo.cc/en-us/products/t-deck-plus-1) was released, and I tinkered with making a backpack for it.  But in the end, the challenges of trying to fit so many sensors into such a small space didn't quite work out -- but I did like the form factor a great deal. 

I ended up not taking too many pictures of this one or its board.

## Iteration 11: Initial Cyberdeck explorations with the Raspberry Pi CMx Tablets

Around this time, Cyberdeck builds started to pop up -- folks were bolting found-keyboards onto found Raspberry Pi compute module-based tablets.  I had a go at building one of these, and these initial iterations are what convinced me that there might be something to the Cyberdeck format.  But there were many problems: It's such a kludge of parts, the keyboards (which are bluetooth!) often have pairing and even powering challenges when you disassemble them, and the whole thing was just *big*.  Most of the room of the huge device was spent trying to get all these large parts to fit together for the console, rather than getting sensors and such in there. 

| Tablet Prototype (1) | Tablet Prototype (2) | Many prototype prints around this time |
| :---: | :---: | :---: |
| <a href="pictures/past-iterations/btree1.JPG">BTree Cyberdeck, picture 1</a> | <a href="pictures/past-iterations/btree2.JPG">BTree Cyberdeck, picture 2</a> | <a href="pictures/past-iterations/btree3.JPG">BTree Cyberdeck, picture 3</a> |

## Iteration 12: A smaller Cyberdeck with the Clockwork Pi PicoCalc

Clockwork Pi released a small cyberdeck called the [PicoCalc](https://www.clockworkpi.com/picocalc), and I was actually fairly convinced that this would be the way forward.  The form factor was smaller than the "found tablet + keyboard", it had a keyboard and a display, and it was very hackable.  But it was based on a small and underpowered microcontroller, which would have significant issues for interfacing with a thermal camera, regular camera, and lots of other peripherals.  So I made a backpack that would replace the microcontroller with a Raspberry Pi Zero W, and use an Arduino as the primary sensor interface.  A 3D printed enclosure ended up being the mount for many of the sensors. 

I actually didn't hate this one, and thought it would be the release.  But the screen resolution (which I think was 320x320, or some other small resolution) ended up just being /too small/ to work with -- you really couldn't easily run X Windows, and I wanted to be able to just use standard software/UI libraries rather than writing everything from scratch again.  So I ended up abandoning this one while it was nearly 90-95% finished.

One (very interesting) aspect of this prototype was focusing on trying to have the visible spectrometer be in transmission mode by default. The big aperture in the side of the device is meant for you to slide a sample container for the spectrometer in it, with a light source on one side, and the spectrometer on the other.  If you wanted to use the spectrometer openly instead of in transmission mode, there'd be a small faux sample container that'd have a mirror in it that would point to the outside world.

There are a few early posts on this one [here on the clockwork pi forum](https://forum.clockworkpi.com/t/raspberry-pi-zero-2-on-picocalc/17946/35). 

| PicoCalc (1) | PicoCalc (2) | PicoCalc (3) | PicoCalc (4) |
| :---: | :---: | :---: | :---: |
| <a href="pictures/past-iterations/picocalc1.jpeg">PicoCalc, picture 1</a> | <a href="pictures/past-iterations/picocalc2.JPG">PicoCalc, picture 2</a> | <a href="pictures/past-iterations/picocalc3.JPG">PicoCalc, picture 3</a> | <a href="pictures/past-iterations/picocalc4.JPG">PicoCalc, picture 4</a> |
| **PicoCalc (5)** | **PicoCalc (6)** |  |  |
| <a href="pictures/past-iterations/picocalc5.JPG">PicoCalc, picture 5</a> | <a href="pictures/past-iterations/picocalc6.JPG">PicoCalc, picture 6</a> |  |  |

## Iteration 13: The Open Source Science Tricoder Cyberdeck

Ultimately the one this repository is about ended up being the one that really worked.  Moving from the `Picocalc` to the `UConsole` provided much more display resolution, and the Raspberry Pi CM4 compute module provided much more compute power than the Raspberry Pi Zero W.  The sensors could be physically added to the back as a sort of custom backpack, rather being all over the place on the Picocalc version, which ended up working very well.

Here are a few early pictures, where I tried to attach a stock cooler -- which ended up needing a truly huge amount of space in the design (so I abandoned it for a time, thinking I wouldn't need a cooler).  It turns out it does run a little warm without a cooler, and would need some kind of cooling in a future iteration.

| Early build (1) | Early build (2) |
| :---: | :---: |
| <a href="pictures/past-iterations/cyberdeck1.JPG">Early build, picture 1</a> | <a href="pictures/past-iterations/cyberdeck2.JPG">Early build, picture 2</a> |

# Errata

## Things that are real errors

1. **Cooling:** The Raspberry Pi compute modules put out real heat, and while you can run them without a cooler for a while, they do get hot -- and will eventually thermally throttle.  This needs some kind of cooling solution, nominally a copper cooler that extends out with a small fan or something similar.

2. **Silkscreen Misprint:** In an earlier version of the ESP32 board (which is shown in the pictures), the white silkscreen text on the PCB swaps which connector should be for the spectrometer, and which connector should be for the magnetic imaging tile.  The connector closest to the middle of the board should be the spectrometer, and the connector closest to the corner of the board should be the magnetic imaging tile. This should be corrected on the latest board file.  

## Things that I just don't like, or that aren't implemented yet

1. **Battery:** The battery does not run for long.  You get maybe an hour or two.  Having smart power features for the sensors would be ideal.
2. **Magnetic Imaging Tile Framerate:** I designed the magnetic imaging tile to have very fast framerates (e.g. up to 20KHz), but the current refresh rate in the interface is only around 1 frame per second.  This is because it's connected to the ESP32, which is constantly polling all sensors in a round-robbin.  The ESP32 firmware needs a separate mode that allows just focusing on the imaging tile for a short while, so that it can record high-speed captures.  It's a minimal amount of work, it's just not implemented yet.
3. **Transmission spectroscopy for visible spectrometer:** I have spent more time than I'm willing to admit thinking about how to put on a proper light source that can be easily mounted/unmounted for transmission spectroscopy.  There is an unused header on the ESP32 breakout for this purpose, but I haven't found a good solution that I like yet.
4. **Wifi Antenna:** I haven't found a great place for the uConsole Wifi antenna yet, which is currently tucked (but not stuck) near the magnetic tile. 
5. **USB Connectors:** It is a genuinely poor design decision for me to use the same QWIIC connectors for the USB hub connectors, because it allows for folks to easily make costly mistakes (e.g. plugging a 3.3V QWIIC connection into a 5V USB connection, and potentially blowing up the QWIIC part).  But the QWIIC connectors and cables were readily available and easy-to-use, and I did it.  My deepest apologies.

# AI Usage

My recollection is that the ESP32 firmware is primarily human written (by me, using libraries authored by myself and others), while the Python user interface is mostly AI generated.  AI models were also used in debugging in the final stages (thank you, Claude, for noticing that I had swapped two pins on the magnetic imaging tile driver, ending my debugging session in an hour instead of many hours). 

# License

The parts of this that are non-code/physical designs (e.g. the 3D prints, the PCBs, the documentation) are licensed [Creative Commons BY 4.0](https://creativecommons.org/licenses/by/4.0/).

The ESP32 firmware essentially stitches together existing libraries with an interface; there is not enough substantial code there to warrant it needing a separate license.  Similarly, the Python user interface is mostly AI generated, and while this is a new legal area, my best understanding is that such code is likely not subject to copyright. 

All of the above is not meant to in any way limit the disclaimer of warranty for all aspects of this project, which is described below.

# Warranty

TLDR: This is a prototype, not a product, and the information in this repository/project may have genuine risks to use.  The author provides no warranty of any kind, and you assume all risks and responsibilities. 

The following is Section 5 of the [Creative Commons Attribution 4.0 International legal code](https://creativecommons.org/licenses/by/4.0/legalcode), reproduced verbatim, and adopted here as the warranty disclaimer for every part of this project (hardware, firmware, software, documentation, etc.):

```
Section 5 -- Disclaimer of Warranties and Limitation of Liability.

  a. UNLESS OTHERWISE SEPARATELY UNDERTAKEN BY THE LICENSOR, TO THE
     EXTENT POSSIBLE, THE LICENSOR OFFERS THE LICENSED MATERIAL AS-IS
     AND AS-AVAILABLE, AND MAKES NO REPRESENTATIONS OR WARRANTIES OF
     ANY KIND CONCERNING THE LICENSED MATERIAL, WHETHER EXPRESS,
     IMPLIED, STATUTORY, OR OTHER. THIS INCLUDES, WITHOUT LIMITATION,
     WARRANTIES OF TITLE, MERCHANTABILITY, FITNESS FOR A PARTICULAR
     PURPOSE, NON-INFRINGEMENT, ABSENCE OF LATENT OR OTHER DEFECTS,
     ACCURACY, OR THE PRESENCE OR ABSENCE OF ERRORS, WHETHER OR NOT
     KNOWN OR DISCOVERABLE. WHERE DISCLAIMERS OF WARRANTIES ARE NOT
     ALLOWED IN FULL OR IN PART, THIS DISCLAIMER MAY NOT APPLY TO YOU.

  b. TO THE EXTENT POSSIBLE, IN NO EVENT WILL THE LICENSOR BE LIABLE
     TO YOU ON ANY LEGAL THEORY (INCLUDING, WITHOUT LIMITATION,
     NEGLIGENCE) OR OTHERWISE FOR ANY DIRECT, SPECIAL, INDIRECT,
     INCIDENTAL, CONSEQUENTIAL, PUNITIVE, EXEMPLARY, OR OTHER LOSSES,
     COSTS, EXPENSES, OR DAMAGES ARISING OUT OF THIS PUBLIC LICENSE OR
     USE OF THE LICENSED MATERIAL, EVEN IF THE LICENSOR HAS BEEN
     ADVISED OF THE POSSIBILITY OF SUCH LOSSES, COSTS, EXPENSES, OR
     DAMAGES. WHERE A LIMITATION OF LIABILITY IS NOT ALLOWED IN FULL OR
     IN PART, THIS LIMITATION MAY NOT APPLY TO YOU.

  c. The disclaimer of warranties and limitation of liability provided
     above shall be interpreted in a manner that, to the extent
     possible, most closely approximates an absolute disclaimer and
     waiver of all liability.
```

# Contact

For questions, please use either Github Issues or `peter@tricorderproject.org` .

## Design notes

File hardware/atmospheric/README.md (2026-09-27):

Note: This atmospheric breakout board is untested.

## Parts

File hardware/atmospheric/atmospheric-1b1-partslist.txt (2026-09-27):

Partlist

Exported	from	atmospheric-1b1.sch	at	6/21/25	4:54	PM

EAGLE	Version	9.6.2	Copyright	(c)	1988-2020	Autodesk,	Inc.

Assembly	variant:	

Part	Value	Device	Package	Library	Sheet

C1	1uF	CAP-0603	0603	SparkFun-Capacitors	1
C2	1uF	CAP-0603	0603	SparkFun-Capacitors	1
C3	1uF	CAP-0603	0603	SparkFun-Capacitors	1
C4	1uF	CAP-0603	0603	SparkFun-Capacitors	1
J1	QWIIC_RIGHT_ANGLE	QWIIC_CONNECTORJS-1MM	JST04_1MM_RA	SparkFun-Connectors	1
J2	QWIIC_RIGHT_ANGLE	QWIIC_CONNECTORJS-1MM	JST04_1MM_RA	SparkFun-Connectors	1
JP1	JUMPER-SMT_3_1-NC_TRACE_SILK	JUMPER-SMT_3_1-NC_TRACE_SILK	SMT-JUMPER_3_1-NC_TRACE_SILK	SparkFun-Jumpers	1
R1	10k	RESISTOR0603	0603	SparkFun-Resistors	1
R2	10k	RESISTOR0603	0603	SparkFun-Resistors	1
R3	10k	RESISTOR0603	0603	SparkFun-Resistors	1
U1	BME680	BME680-LGA	LGA3.0X3.0	SparkFun-Sensors	1
U2	SCD4X	SCD4X	SCD4X	notes1a	1

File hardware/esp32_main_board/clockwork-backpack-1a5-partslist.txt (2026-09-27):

Partlist

Exported from clockwork-backpack-1a4.sch at 1/8/26 11:38 AM

EAGLE Version 9.6.2 Copyright (c) 1988-2020 Autodesk, Inc.

Assembly variant: 

Part     Value             Device                Package           Library             Sheet

C1       1uF               CAP-0603              0603              SparkFun-Capacitors 1
C2       1uF               CAP-0603              0603              SparkFun-Capacitors 1
C3       100uF             CAP-1206              1206              SparkFun-Capacitors 1
C4       100uF             CAP-1206              1206              SparkFun-Capacitors 1
C5       100uF             CAP-1206              1206              SparkFun-Capacitors 1
C6       100uF             CAP-1206              1206              SparkFun-Capacitors 1
CN1      CON-SM08B-SRSS-TB CON-SM08B-SRSS-TB     CON-SM08B-SRSS-TB notes1a             1
CN2      CON-SM08B-SRSS-TB CON-SM08B-SRSS-TB     CON-SM08B-SRSS-TB notes1a             1
CN3      QWIIC_RIGHT_ANGLE QWIIC_CONNECTORJS-1MM JST04_1MM_RA      SparkFun-Connectors 1
CN4                        CONN_05LOCK           1X05_LOCK         SparkFun-Connectors 1
CN5                        CONN_05LOCK           1X05_LOCK         SparkFun-Connectors 1
U1       TXS0108EPWR       TXS0108EPWR           TSSOP-20          notes1a             1
U2       FEATHERWING_NODIM FEATHERWING_NODIM     FEATHERWING_DIM   notes1a             1

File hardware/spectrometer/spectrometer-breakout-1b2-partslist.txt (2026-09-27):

Partlist

Exported	from	spectrometer-breakout-1c2.sch	at	6/21/25	4:54	PM

EAGLE	Version	9.6.2	Copyright	(c)	1988-2020	Autodesk,	Inc.

Assembly	variant:	

Part	Value	Device	Package	Library	Sheet

C1	0.022uF	CAP-0603	0603	SparkFun-Capacitors	1
C2	0.022uF	CAP-0603	0603	SparkFun-Capacitors	1
C3	4.7uF	CAP-0603	0603	SparkFun-Capacitors	1
J1	CON-SM08B-SRSS-TB	CON-SM08B-SRSS-TB	CON-SM08B-SRSS-TB	notes1a	1
L1	100uH	INDUCTORDNP	0603	SparkFun-Coils	1
R1	1.7k	(prec.)	RESISTOR0603	0603	SparkFun-Resistors	1
R2	3.3k	(prec.)	RESISTOR0603	0603	SparkFun-Resistors	1
U1	OPA344NA/250	OPA344NA/250	SOT3-5	notes1a	1
U2	C12666MA	C12666MA	C12666MA	notes1a	1

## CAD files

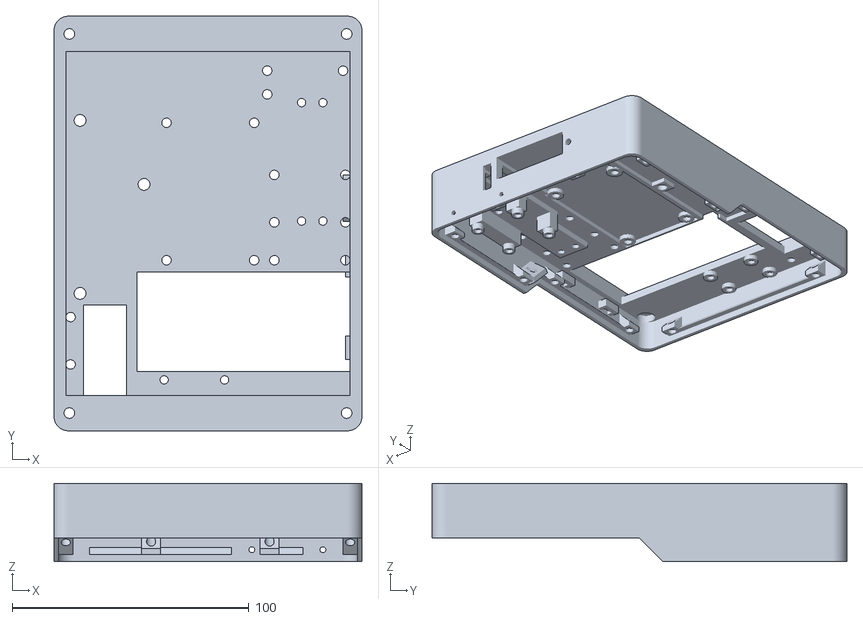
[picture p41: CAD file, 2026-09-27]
openscad/main_body.stl
130.0 x 175.0 x 33.0

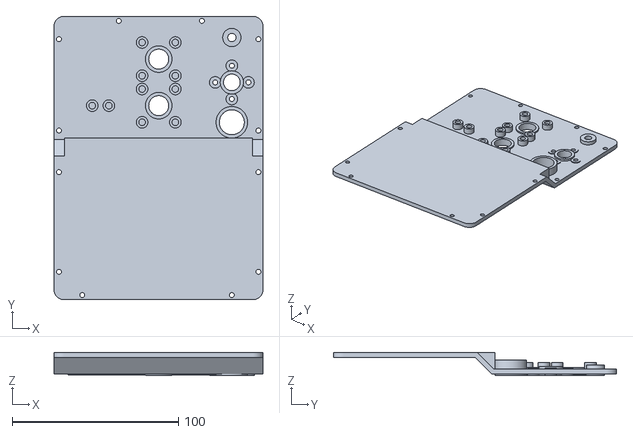
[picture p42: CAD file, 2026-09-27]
openscad/back_cover.stl
125.8 x 170.5 x 14.0

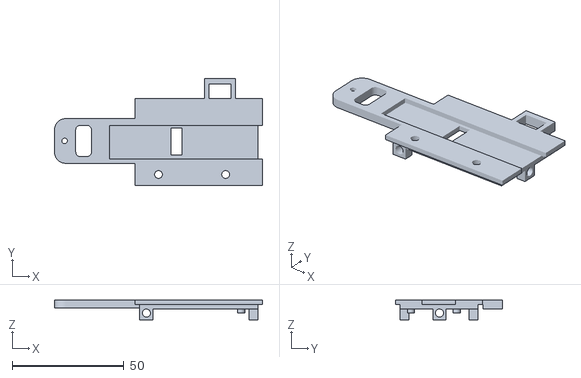
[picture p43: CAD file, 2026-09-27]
openscad/magtile_back.stl
93.0 x 48.0 x 8.75

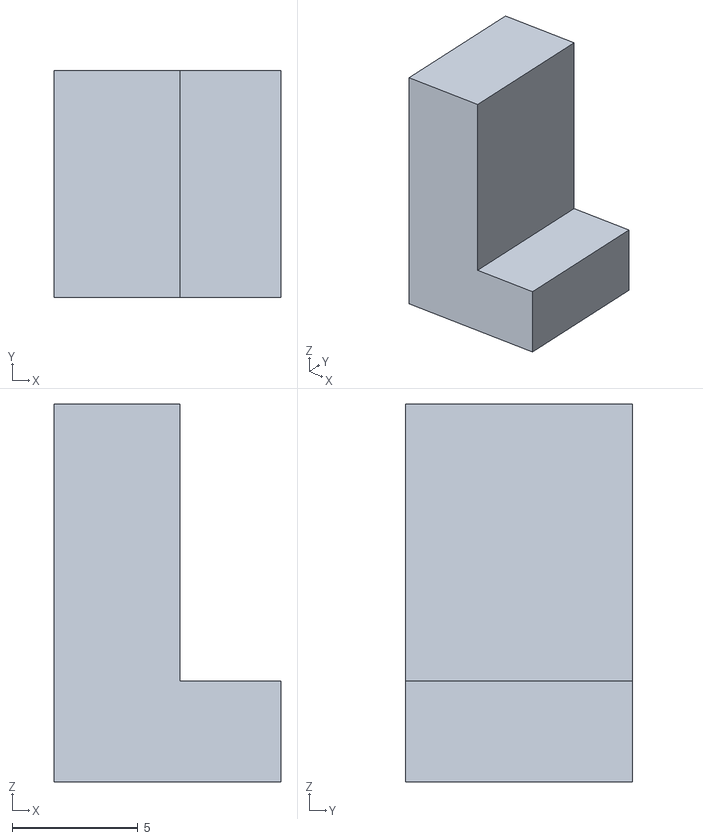
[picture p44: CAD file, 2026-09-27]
openscad/powerbutton.stl
9.00 x 9.00 x 15.0

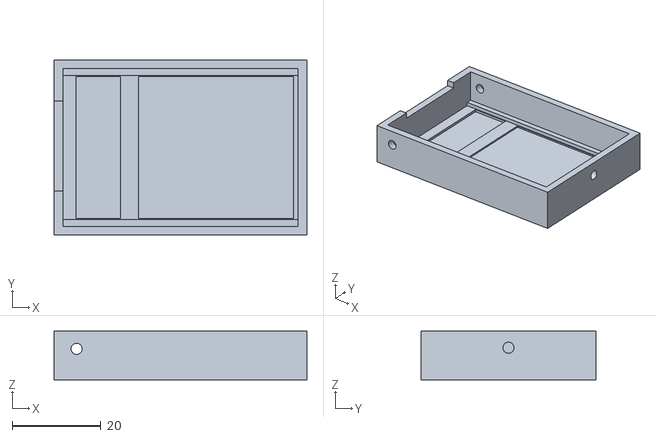
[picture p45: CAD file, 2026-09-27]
openscad/magtile_front.stl
57.0 x 39.5 x 11.0

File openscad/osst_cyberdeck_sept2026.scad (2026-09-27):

// Increase $fn for smoother corners (optional)
$fn = 64;


width = 130.0;
length = 175.0;
thickness = 8.0;

screw_w = 117.0;
screw_l = 160.0;

screw_dia = 4.5;

case_corner_radius = 6.0;


// Module: create a 2D rounded‐rectangle of width=w, height=h and corner‐radius=r
module roundedRect2D(w, h, r) {
    // The inner square is (w−2r)×(h−2r).  Minkowski with a circle of radius=r adds
    // the rounded corners (and expands back to w×h overall).
    translate([r, r, 0]) {
        minkowski() {
            square([w - 2*r, h - 2*r], center = false);
            circle(r = r);
        }
    }
}

module right_triangle_45_45_90_x(leg=2, length=200, center=false) {
    rotate([0, 90, 0])
        linear_extrude(height=length, center=center)
            polygon(points=[
                [0,0],
                [leg,leg],
                [0,leg]
            ]);
}

module right_triangle_45_45_90_y(leg=2, length=200, center=false) {
    rotate([-90, 0, 0])
        linear_extrude(height=length, center=center)
            polygon(points=[
                [0,0],
                [leg,leg],
                [0,leg]
            ]);
}

module right_triangle_45_45_90_z(leg=2, length=200, center=false) {
    linear_extrude(height=length, center=center)
        polygon(points=[
            [0,0],
            [leg,leg],
            [0,leg]
        ]);
}

module right_triangle_45_45_90_x_mirror(leg=2, length=200, center=false) {
    mirror([0,1,0])
        right_triangle_45_45_90_x(leg=leg, length=length, center=center);
}

module right_triangle_45_45_90_y_mirror(leg=2, length=200, center=false) {
    mirror([1,0,0])
        right_triangle_45_45_90_y(leg=leg, length=length, center=center);
}

module right_triangle_45_45_90_z_mirror(leg=2, length=200, center=false) {
    mirror([0,0,1])
        right_triangle_45_45_90_z(leg=leg, length=length, center=center);
}


module mkScrewMountTriangle(mode="positive", length=8) {
    insert_dia = 3.9;    
    
    if (mode == "positive") {
        color("orange") 
        difference() {
            union() {
                right_triangle_45_45_90_y(leg=6, length=length, center=false);    
                translate([0, 0, -8.5]) cube([6, length, 2.5]);  // Add some to top
            }   
            translate([6/2, length/2, -8-0.5-0.1]) cylinder(h=7+1, d=insert_dia);
        }
    } else if (mode == "negative") {
        // Redo the insert cut
        translate([6/2, length/2, -8-0.5-0.1]) cylinder(h=7+1, d=insert_dia);
    }
        
}


module mkScrewMountCover(mode="positive", length=8) {
    screw_dia = 3;    
    
    if (mode == "positive") {
        // Currently unused
        /*
        color("orange") 
        difference() {
            union() {
                right_triangle_45_45_90_y(leg=6, length=length, center=false);    
                translate([0, 0, -8.5]) cube([6, length, 2.5]);  // Add some to top
            }   
            translate([6/2, length/2, -8-0.5-0.1]) cylinder(h=7+1, d=insert_dia);
        }
        */
        
    } else if (mode == "negative") {
        // Redo the insert cut
        translate([6/2, length/2, -8-0.5-0.1]) cylinder(h=7+1, d=screw_dia);
    }
        
}



module mkCableChannel() {
    difference() {
        cube([5, 10, 4]);
        translate([2.51, 2.5, -1]) color("blue") cube([2.5, 5, 6]);
    }
    
    /*
    inner_height = 5.0;
    thickness = 9.0;
    depth = 6.0;
    
    difference() {
        cube([depth, thickness, inner_height+6]);
        hull() {
            translate([0, thickness+1, (inner_height+6)/2]) rotate([90, 0, 0]) cylinder(d=inner_height, h=thickness+2);
            translate([depth-2, thickness+1, (inner_height+6)/2]) rotate([90, 0, 0]) cylinder(d=inner_height, h=thickness+2);
        }
    }   
    
    translate([1, (thickness-4)/2, -1]) color("blue") cube([2, 4, inner_height+6+2]);
    */
}

module mkBackCrossbrace() {
    side_size = 2.0;
    lengthc = 14.0;
    widthc = width - (2*side_size) - 0.25;
    
    difference() {
    union() {
    translate([side_size, 0, 0]) {         
        difference() {        
        union() {
        rotate([-45, 0, 0]) {
            difference() {
                // Main piece
                color("blue") cube([widthc, lengthc, 3]);
                // Screw holes
                translate([3, (lengthc/2)-1, -1]) color("red") cylinder(d=3, h=3+2);
                translate([widthc-3, (lengthc/2)-1, -1]) color("red") cylinder(d=3, h=3+2);
                               
            }            
        }
        
        // Main piece with 2 bolt holes
        translate([6.25, -0, 3]) { 
            right_triangle_45_45_90_x(leg=12, length=widthc-(6.25*2));
            cube([widthc-(6.25*2), 12, 2]);
        }
        }
        
        
        // Top (cut off)
        translate([0, 10, -10]) {
            cube([widthc, 3, 3]);
        }
        }
        
        // Bottom
        cube([widthc, 3, 3]);
        
    }
    
    // Holder (bottom)
    brass_insert_dia = 3.9;
      
    translate([(widthc/2)-7.5, -7, 3]) {
        difference() {
            cube([10, 10, 4]);
            translate([5, 3, -1]) color("red") cylinder(d=brass_insert_dia, h=4+2);
        }
    }
    

    // Rim (bottom)
    translate([side_size+10, -2, 3]) {
            cube([widthc-20, 5, 2]);                    
    }


    // Holder (bottom)    
    translate([(widthc/2)-7.5, 7, -10+3]) {
        difference() {
            cube([10, 12, 4]);
            translate([5, 10-2, -1]) color("red") cylinder(d=brass_insert_dia, h=4+2);
        }
    }

    // Rim (top)
    translate([side_size+10, 8, -10+3]) {
            cube([widthc-20, 5, 2]);                    
    }
    }
    
    // Cut off a small part on the bottom of the sides at a 45 degree angle
    // One side
    translate([side_size-0.1, 0, 4.24]) {
        color("purple") rotate([-45, 0, 0]) cube([6.35, 5, 5]);        
    }
    // Other side
    translate([widthc-8+3.75, 0, 4.24]) {
        color("purple") rotate([-45, 0, 0]) cube([6.5, 5, 5]);        
    }
    
    // Center cutout    
    translate([(widthc/2)+2.5, -7, 3]) color("purple") cube([15, 30, 4]);

    }

    
    
}

module mkBackCover1() {
    side_size = 2.0;
    lengthc = 14.0;
    widthc = width - (2*side_size) - 0.25;
    
    //roundedRect2D(width-(2*side_size), length-(2*side_size), r=case_corner_radius);  // 5mm corner radius
    
    difference() {
    union() {
    translate([side_size, 0, 0]) {         
        difference() {        
        union() {
        rotate([-45, 0, 0]) {
            difference() {
                // Main piece
                color("blue") cube([widthc, lengthc, 3]);
                // Screw holes
                //translate([3, (lengthc/2)-1, -1]) color("red") cylinder(d=3, h=3+2);
                //translate([widthc-3, (lengthc/2)-1, -1]) color("red") cylinder(d=3, h=3+2);
                               
            }            
        }
        
        // Main piece with 2 bolt holes
        translate([6.25, -0, 3]) right_triangle_45_45_90_x(leg=12, length=widthc-(6.25*2));                    
        }
        
        }
        
        // Bottom
        cube([widthc, 3, 3]);
        
        // Top plate
        translate([0, 10, -10]) {  
            color("purple")  union() {
            linear_extrude(height = 3) {
                roundedRect2D(widthc, (length/2)-10-side_size-0.25, r=case_corner_radius);  // 5mm corner radius
            }
            cube([widthc, 10, 3]);
            }
        }
        
        // Bottomplate
        color("purple") union() {
        translate([0, -(length/2)+side_size+0.25, -0]) {                        
             linear_extrude(height = 3) {
                roundedRect2D(widthc, (length/2)-side_size-0.25, r=case_corner_radius);  // 5mm corner radius
            }            
        }
        translate([0, -10, -0]) cube([widthc, 10, 3]);
        }
        
        
        // Circles: Sensor Apertures
        translate([-side_size, -length/2, 18-3.5-0.5]) {        
            // Thermal camera
            translate([width-2-19, 100+5+4, -25]) cylinder(d=15+4, h=6+3.5);
            // Visible camera
            translate([width-2-19, 100+5+4+24, -25]) cylinder(d=10+4, h=3+3.5-1);      // Camera
            translate([width-2-19, 100+5+4+24+10, -25]) cylinder(d=3+4, h=1+3.5);    // Microphone 1
            translate([width-2-19, 100+5+4+24-10, -25]) cylinder(d=3+4, h=1+3.5);    // Microphone 2
            translate([width-2-19+10, 100+5+4+24, -25]) cylinder(d=3+4, h=1+3.5);    // Microphone 1
            translate([width-2-19-10, 100+5+4+24, -25]) cylinder(d=3+4, h=1+3.5);    // Microphone 2
            
            // Spectrometer
            translate([width-2-19, 100+5+4+24+27, -25]) cylinder(d=5+6, h=6+3.5-3);
        }
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

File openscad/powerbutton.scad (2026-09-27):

cube([5, 9, 15]);
cube([5+4, 9, 4]);

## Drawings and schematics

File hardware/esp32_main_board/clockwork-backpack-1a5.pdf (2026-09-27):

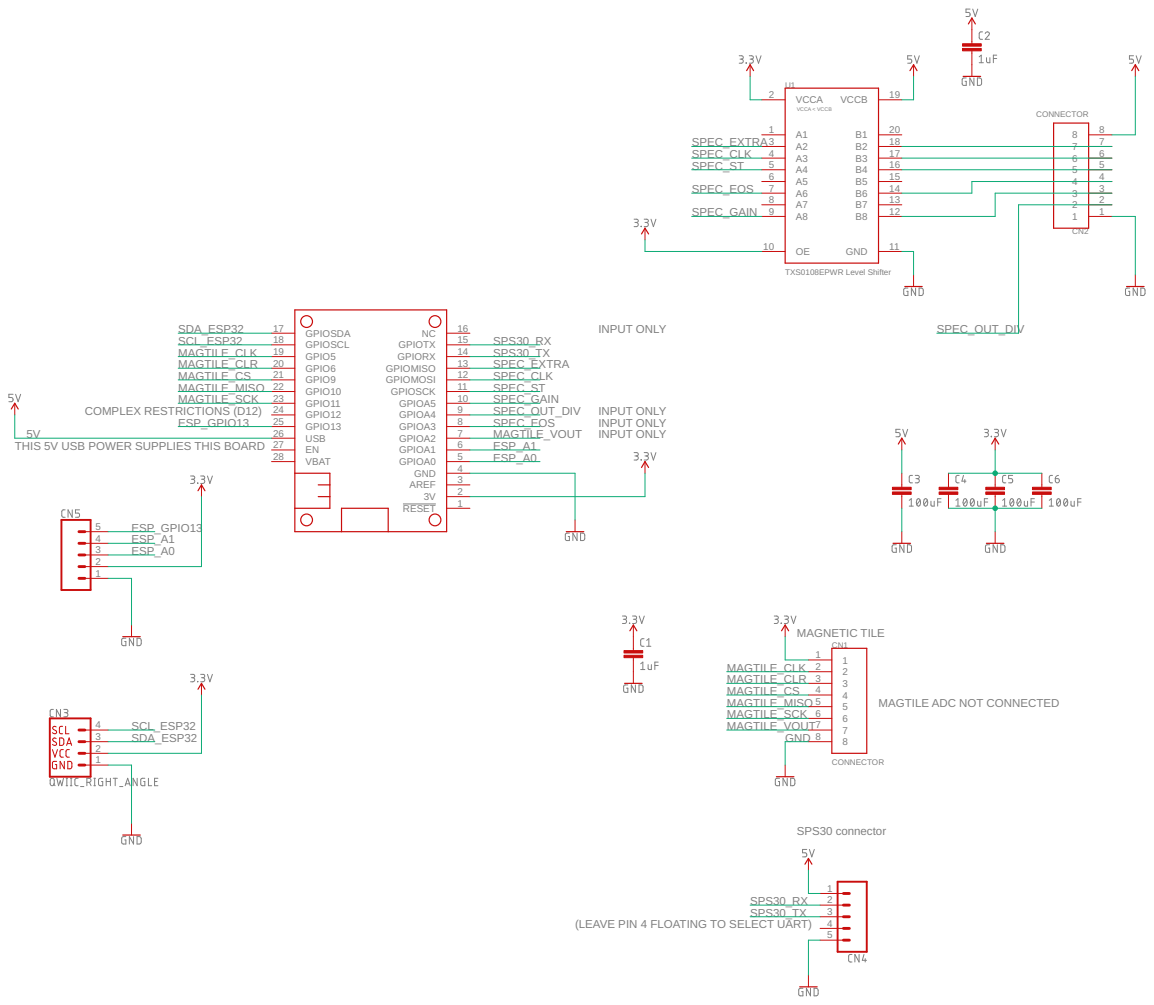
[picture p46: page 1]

INPUT ONLY COMPLEX RESTRICTIONS (D12)

THIS 5V USB POWER SUPPLIES THIS BOARD

MAGNETIC TILEMAGTILE ADC NOT CONNECTED

(LEAVE PIN 4 FLOATING TO SELECT UART)

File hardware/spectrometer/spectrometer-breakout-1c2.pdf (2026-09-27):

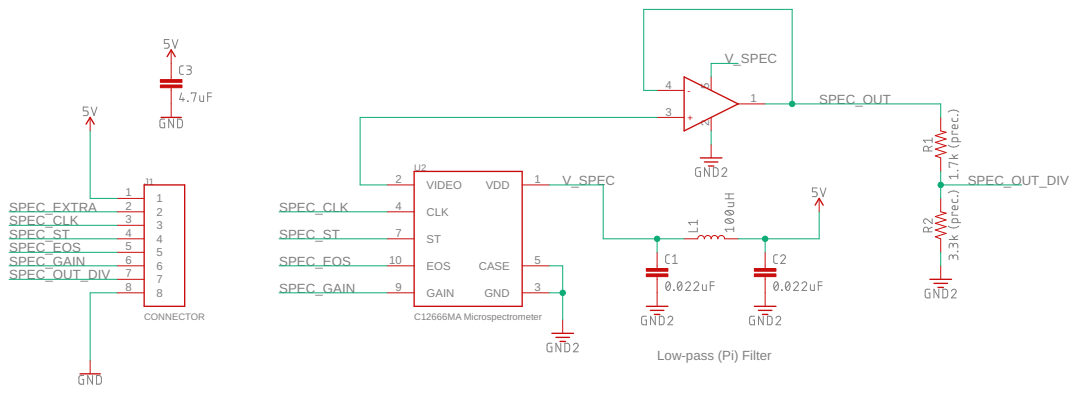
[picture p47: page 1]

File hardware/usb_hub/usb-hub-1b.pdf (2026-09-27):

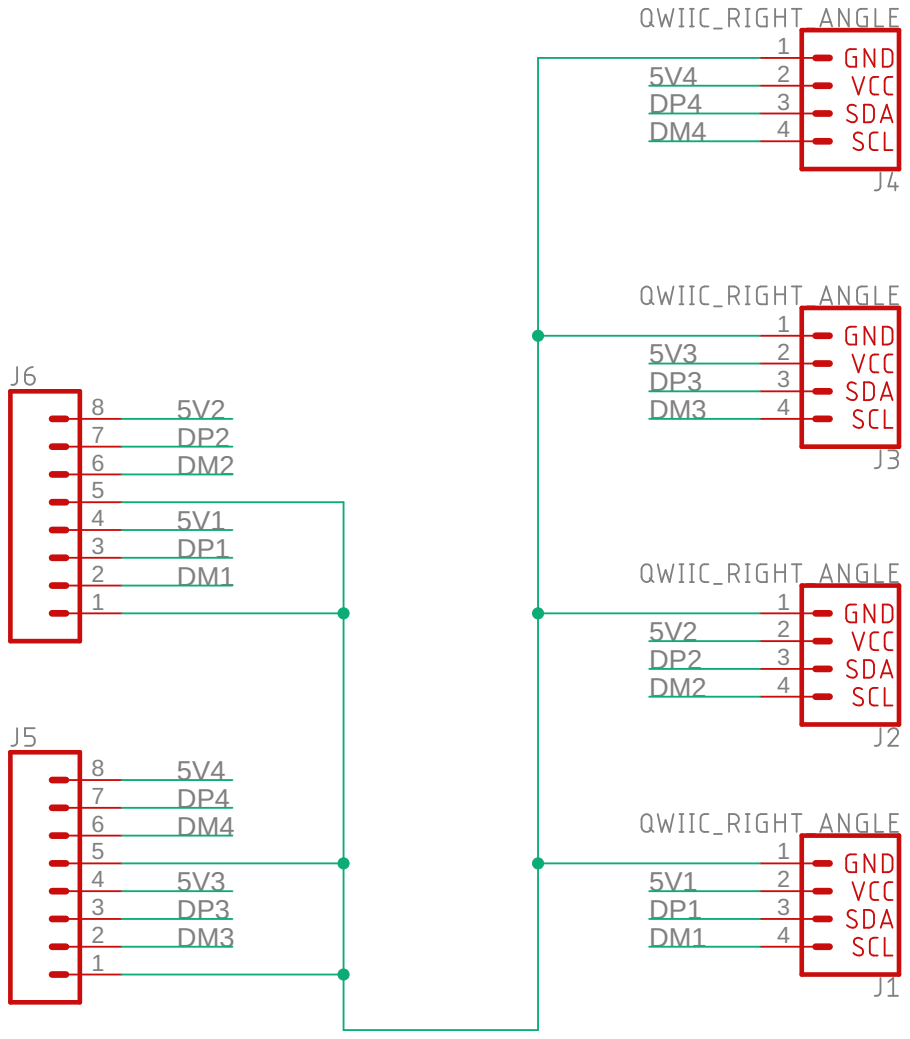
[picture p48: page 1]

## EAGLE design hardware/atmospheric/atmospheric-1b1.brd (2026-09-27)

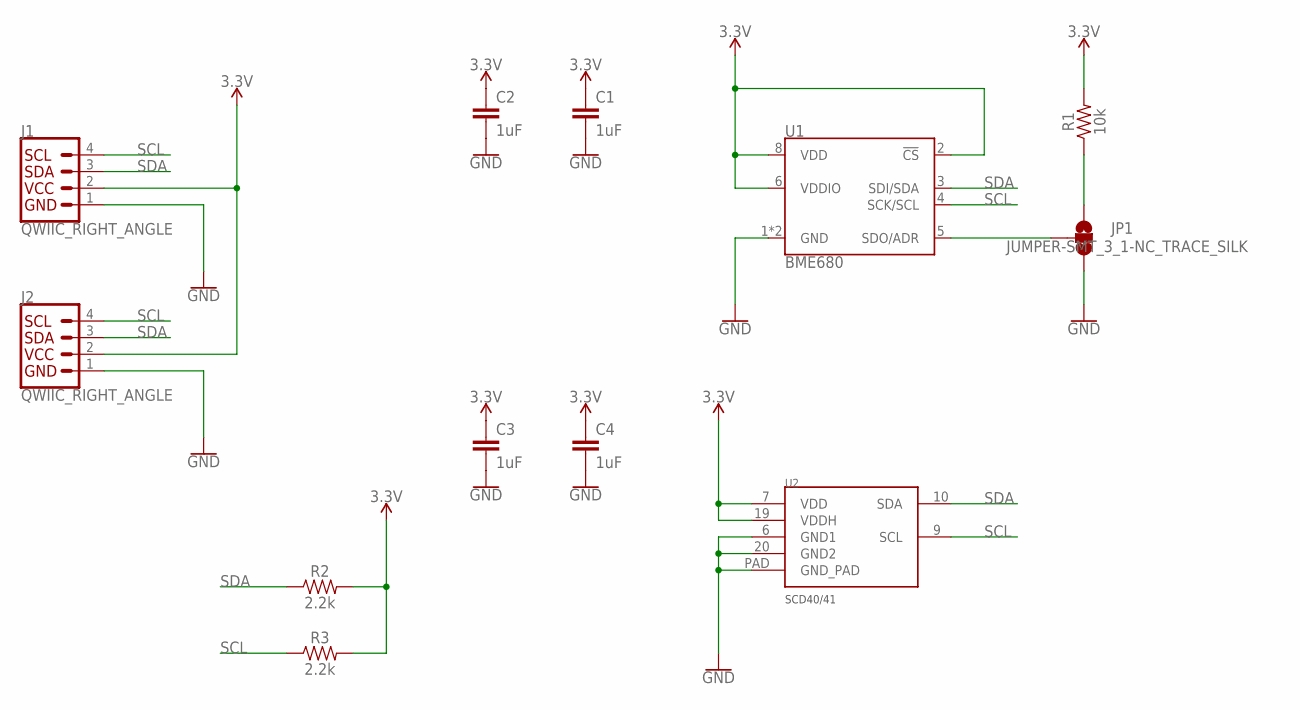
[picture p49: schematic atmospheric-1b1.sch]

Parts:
C1, C2, C3, C4: 1uF; 0603
J1, J2: QWIIC_RIGHT_ANGLE; JST04_1MM_RA
JP1: JUMPER-SMT_3_1-NC_TRACE_SILK; SMT-JUMPER_3_1-NC_TRACE_SILK
R1: 10k; 0603
R2, R3: 2.2k; 0603
U1: BME680; LGA3.0X3.0
U2: SCD4X

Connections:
3.3V: C1.1, C2.1, C3.1, C4.1, J1.2, J2.2, R1.2, R2.2, R3.2, U1.2 (!CS), U1.6 (VDDIO), U1.8 (VDD), U2.7 (VDD), U2.19 (VDDH)
GND: C1.2, C2.2, C3.2, C4.2, J1.1, J2.1, JP1.3, U1.1 (GND), U1.7 (GND), U2.6 (GND1), U2.20 (GND2), U2.PAD (GND_PAD)
unnamed: JP1.2, U1.5 (SDO/ADR)
unnamed: JP1.1, R1.1
SCL: J1.4, J2.4, R3.1, U1.4 (SCK/SCL), U2.9 (SCL)
SDA: J1.3, J2.3, R2.1, U1.3 (SDI/SDA), U2.10 (SDA)

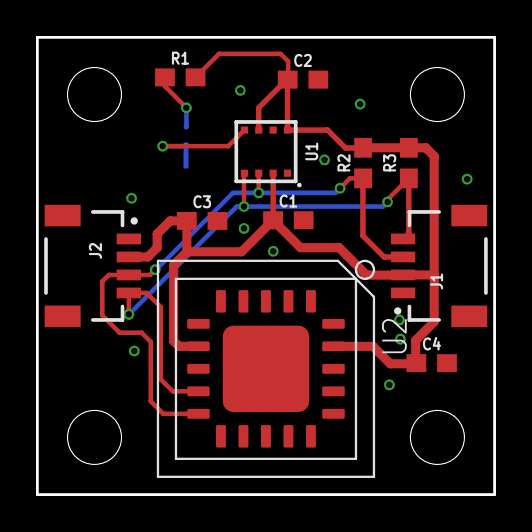
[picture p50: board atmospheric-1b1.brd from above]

Board: 2 copper layers, 25.4 x 25.4 mm, 12 parts (1 on the bottom side), 6 nets.

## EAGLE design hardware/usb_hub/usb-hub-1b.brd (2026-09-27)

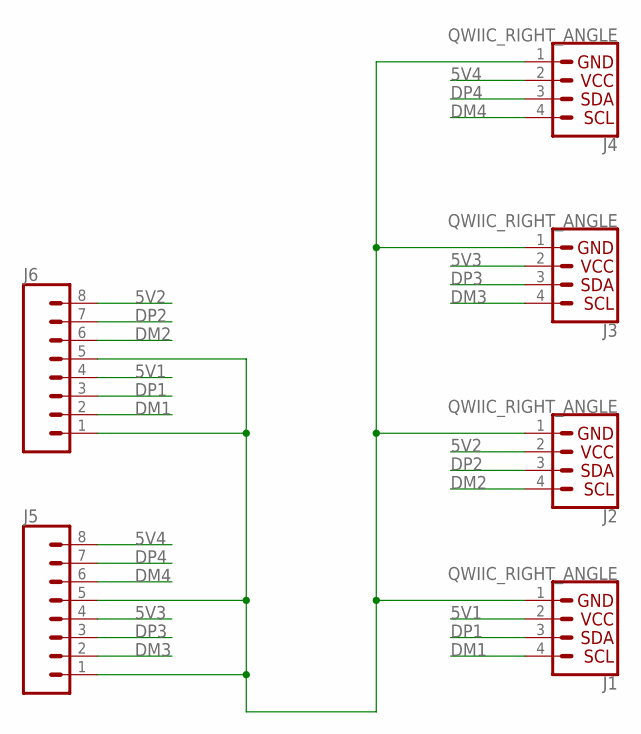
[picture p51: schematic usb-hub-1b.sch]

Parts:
J1, J2, J3, J4: QWIIC_RIGHT_ANGLE; JST04_1MM_RA
J5, J6: CONN_08LOCK; 1X08_LOCK

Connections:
5V1: J1.2, J6.4
5V2: J2.2, J6.8
5V3: J3.2, J5.4
5V4: J4.2, J5.8
DM1: J1.4, J6.2
DM2: J2.4, J6.6
DM3: J3.4, J5.2
DM4: J4.4, J5.6
DP1: J1.3, J6.3
DP2: J2.3, J6.7
DP3: J3.3, J5.3
DP4: J4.3, J5.7
GND: J1.1, J2.1, J3.1, J4.1, J5.1, J5.5, J6.1, J6.5

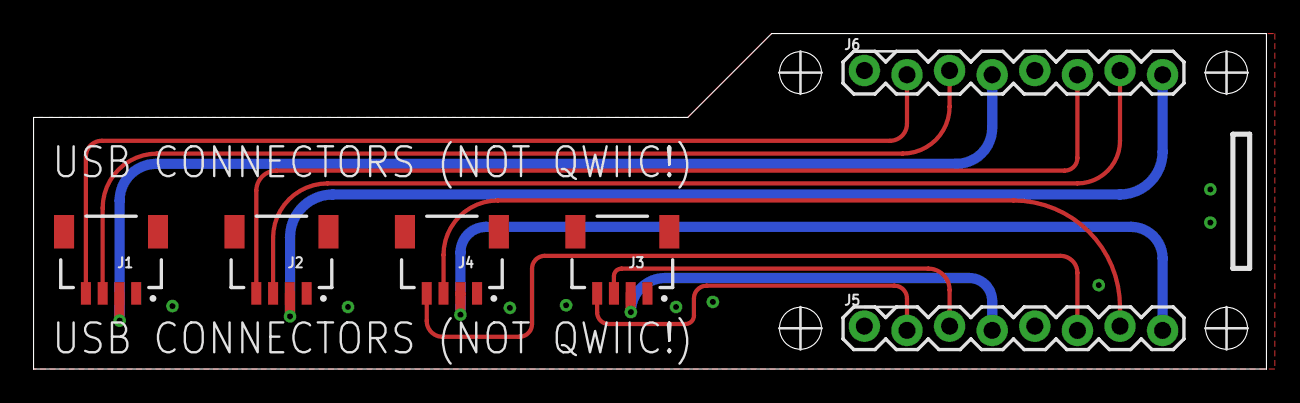
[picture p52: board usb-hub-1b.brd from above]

Board: 2 copper layers, 73.5 x 20.0 mm, 6 parts (0 on the bottom side), 13 nets.

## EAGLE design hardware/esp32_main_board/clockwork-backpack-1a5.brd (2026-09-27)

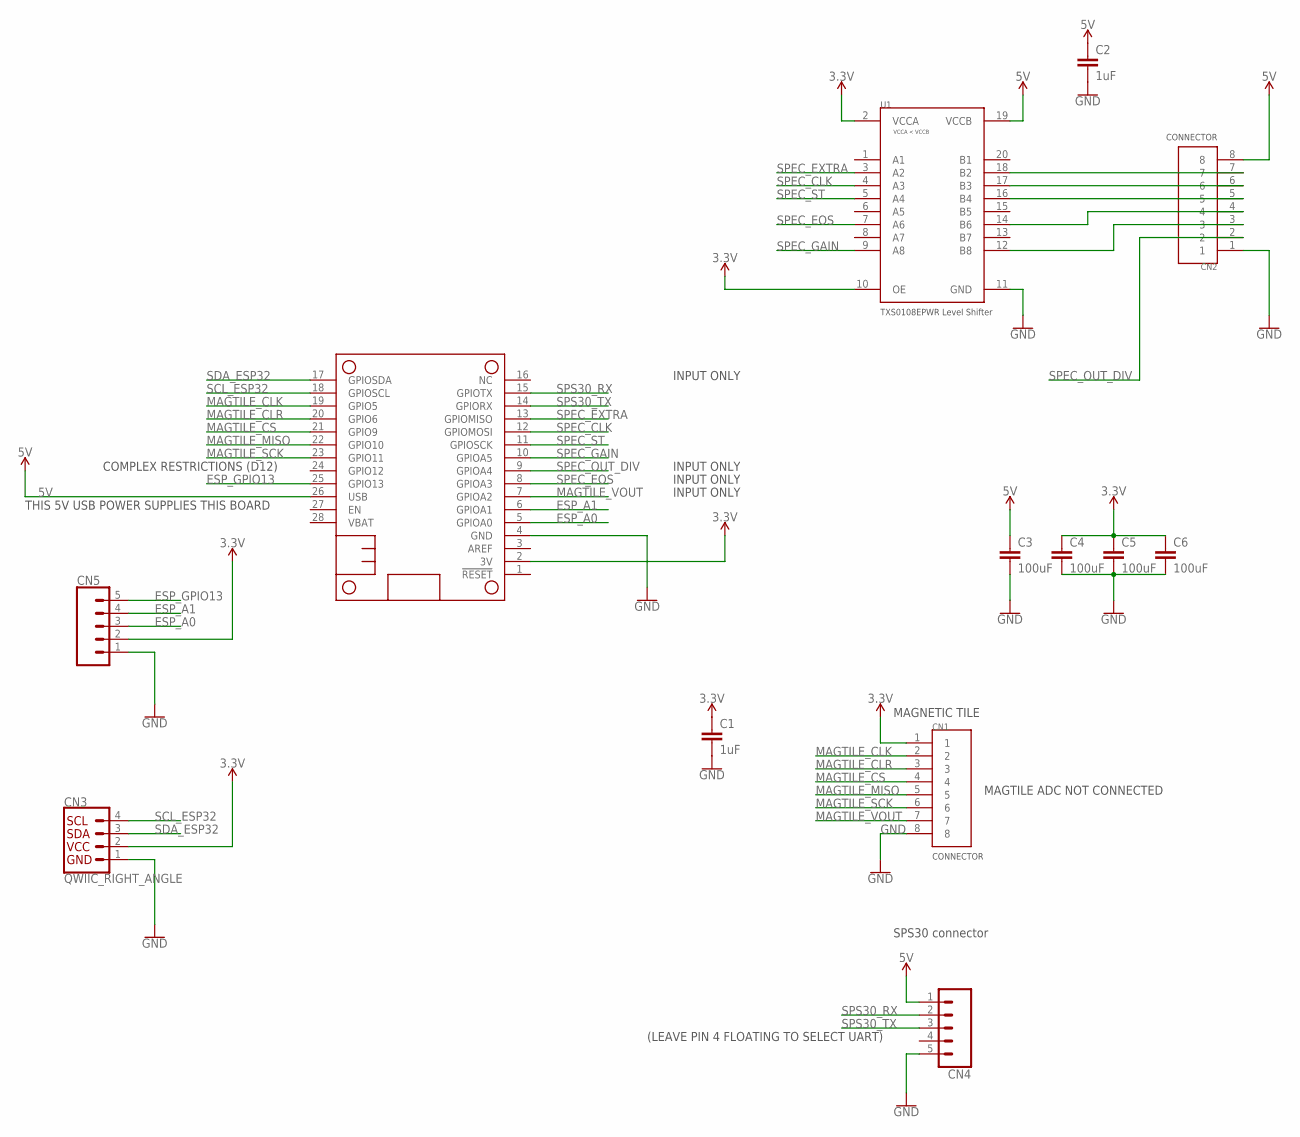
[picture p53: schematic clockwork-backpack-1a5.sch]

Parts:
C1, C2: 1uF; 0603
C3, C4, C5, C6: 100uF; 1206
CN1, CN2: CON-SM08B-SRSS-TB
CN3: QWIIC_RIGHT_ANGLE; JST04_1MM_RA
CN4, CN5: CONN_05LOCK; 1X05_LOCK
U1: TXS0108EPWR; TSSOP-20
U2: FEATHERWING_NODIM; FEATHERWING_DIM

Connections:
3.3V: C1.1, C4.1, C5.1, C6.1, CN1.1, CN3.2, CN5.2, U1.2 (VCCA), U1.10 (OE), U2.2 (3V)
5V: C2.1, C3.1, CN2.8, CN4.1, U1.19 (VCCB), U2.26 (USB)
ESP_A0: CN5.3, U2.5 (GPIOA0)
ESP_A1: CN5.4, U2.6 (GPIOA1)
ESP_GPIO13: CN5.5, U2.25 (GPIO13)
GND: C1.2, C2.2, C3.2, C4.2, C5.2, C6.2, CN1.8, CN2.1, CN3.1, CN4.5, CN5.1, U1.11 (GND), U2.4 (GND)
MAGTILE_CLK: CN1.2, U2.19 (GPIO5)
MAGTILE_CLR: CN1.3, U2.20 (GPIO6)
MAGTILE_CS: CN1.4, U2.21 (GPIO9)
MAGTILE_MISO: CN1.5, U2.22 (GPIO10)
MAGTILE_SCK: CN1.6, U2.23 (GPIO11)
MAGTILE_VOUT: CN1.7, U2.7 (GPIOA2)
unnamed: CN2.7, U1.18 (B2)
unnamed: CN2.3, U1.12 (B8)
unnamed: CN2.4, U1.14 (B6)
unnamed: CN2.6, U1.17 (B3)
unnamed: CN2.5, U1.16 (B4)
SCL_ESP32: CN3.4, U2.18 (GPIOSCL)
SDA_ESP32: CN3.3, U2.17 (GPIOSDA)
SPEC_CLK: U1.4 (A3), U2.12 (GPIOMOSI)
SPEC_EOS: U1.7 (A6), U2.8 (GPIOA3)
SPEC_EXTRA: U1.3 (A2), U2.13 (GPIOMISO)
SPEC_GAIN: U1.9 (A8), U2.10 (GPIOA5)
SPEC_OUT_DIV: CN2.2, U2.9 (GPIOA4)
SPEC_ST: U1.5 (A4), U2.11 (GPIOSCK)
SPS30_RX: CN4.2, U2.15 (GPIOTX)
SPS30_TX: CN4.3, U2.14 (GPIORX)

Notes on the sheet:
SPS30 connector
MAGNETIC TILE
MAGTILE ADC NOT CONNECTED
INPUT ONLY
COMPLEX RESTRICTIONS (D12)
(LEAVE PIN 4 FLOATING TO SELECT UART)
THIS 5V USB POWER SUPPLIES THIS BOARD

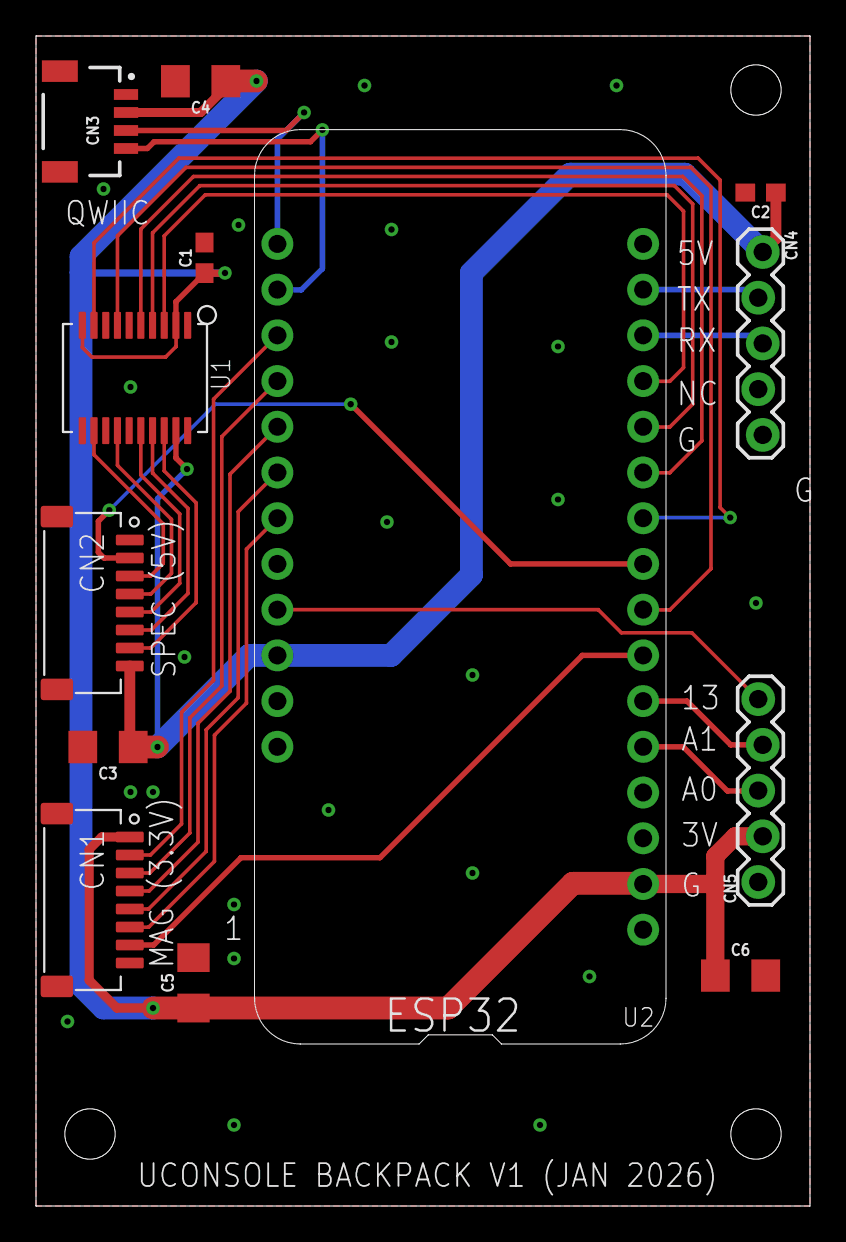
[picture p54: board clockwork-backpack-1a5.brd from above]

Board: 2 copper layers, 43.0 x 65.0 mm, 13 parts (0 on the bottom side), 27 nets.

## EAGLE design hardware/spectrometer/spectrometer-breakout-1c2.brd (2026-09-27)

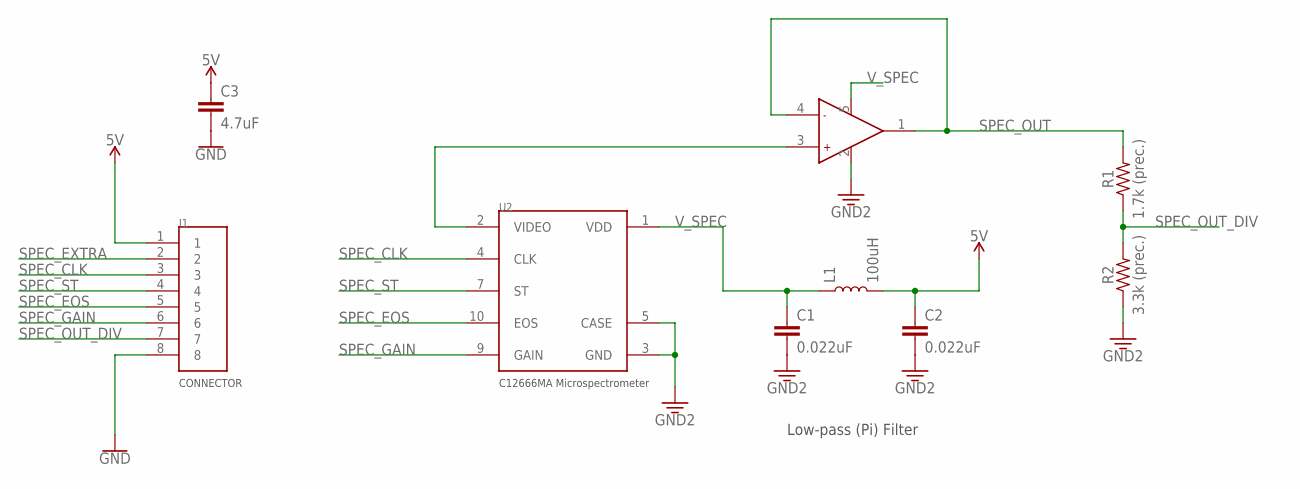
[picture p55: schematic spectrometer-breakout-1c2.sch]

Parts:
C1, C2: 0.022uF; 0603
C3: 4.7uF; 0603
J1: CON-SM08B-SRSS-TB
L1: 100uH; 0603
R1: 1.7k (prec.); 0603
R2: 3.3k (prec.); 0603
U1: OPA344NA/250; SOT3-5
U2: C12666MA

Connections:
5V: C2.1, C3.1, J1.1, L1.2
GND: C1.2, C2.2, C3.2, J1.8, R2.1, U1.2 (GND), U2.3 (GND), U2.5 (CASE)
unnamed: U1.3 (+), U2.2 (VIDEO)
SPEC_CLK: J1.3, U2.4 (CLK)
SPEC_EOS: J1.5, U2.10 (EOS)
SPEC_EXTRA: J1.2
SPEC_GAIN: J1.6, U2.9 (GAIN)
SPEC_OUT: R1.2, U1.1 (OUT), U1.4 (-)
SPEC_OUT_DIV: J1.7, R1.1, R2.2
SPEC_ST: J1.4, U2.7 (ST)
V_SPEC: C1.1, L1.1, U1.5 (VCC), U2.1 (VDD)

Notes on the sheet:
Low-pass (Pi) Filter

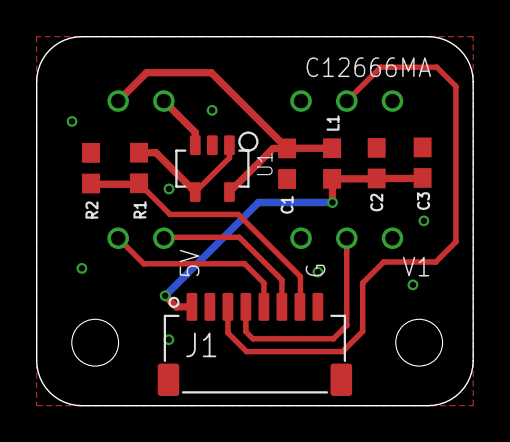
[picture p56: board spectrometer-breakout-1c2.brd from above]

Board: 2 copper layers, 24.2 x 20.5 mm, 9 parts (1 on the bottom side), 10 nets.

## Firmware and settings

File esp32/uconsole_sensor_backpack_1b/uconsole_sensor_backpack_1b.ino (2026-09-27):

// Example of testing all the sensors for the backpack


#include "tfminiplus.h"
#include <Adafruit_MLX90640.h>
#include "SparkFun_SCD4x_Arduino_Library.h" //Click here to get the library: http://librarymanager/All#SparkFun_SCD4x
#include <Adafruit_Sensor.h>
#include "Adafruit_BME680.h"
#include "Adafruit_MLX90393.h"

#include "SensorBuffer.h"
#include "SensorRadiation.h"

#include "SensorSpecHamamatsu.h"


#include "sps30.h"


#define PIN_3V_ENABLE 25
#define PIN_5V_ENABLE 26

// Firmware version, reported at the end of setup()
#define FIRMWARE_VERSION "1b.1"

// SPS30 particle sensor
SPS30 sensorSPS30;

// Hamamatsu Spectrometer
SensorSpecHamamatsu sensorSpec;

/*
// Constants/Globals
Adafruit_MLX90640 mlx;
float mlx90640_frame[32*24]; // buffer for full frame of temperatures
//#define PRINT_ASCIIART
#define PRINT_TEMPERATURES
*/

SCD4x sensorSCD4x;

// BME688
#define SEALEVELPRESSURE_HPA (1013.25)
Adafruit_BME680 bme(&Wire); // I2C

// MLX90393
Adafruit_MLX90393 mlx90393 = Adafruit_MLX90393();

// Radiation Watch Type 5
//SensorBuffer sbRad(100);
//SensorRadiation sensorRadiation(&sbRad);
//SensorRadiation sensorRadiation;
int DIGIPOT_UD  = 33;
int DIGIPOT_CS  = 15;


// Magnetic Imaging Tile
#define CS_INACTIVE  1
#define CS_ACTIVE    0

//Hardware connections
const byte PIN_ANALOG = A2;

// Pin mapping for the clockwork-backpack-1a4 main board with a SparkFun ESP32 Thing Plus C in the
// Feather socket.  The schematic labels the socket by Feather position (GPIO5, GPIO6, GPIO9, ...);
// the ESP32 GPIO that the Thing Plus C actually has at each of those positions is used here.
//   Feather pos.  Thing Plus C GPIO   Tile signal
//   GPIO5         14                  CLK  (counter clock)
//   GPIO6         32                  CLR  (counter clear)
//   GPIO9         15                  CS   (AD7680, unused)
//   GPIO10        33                  MISO (AD7680, unused)
//   GPIO11        27                  SCK  (AD7680, unused)
//   A2            34                  OUT  (analog)
#define PIN_CLR   32
#define PIN_CLK   14
/*
const byte AD7940_SPI_MISO = 33;
const byte AD7940_SPI_CS = 15;
const byte AD7940_SPI_CLK = 27;
*/

// Frames
//#if defined(__AVR_ATmega328P__) || defined(__AVR_ATmega168__)

//We have very limited RAM
//#define MAX_BASE_FRAMES  2

//#else

//Platforms like SAMD21, ChipKit, and Teensy have far more RAM
//#define MAX_BASE_FRAMES  500
//#define MAX_BASE_FRAMES  250
#define MAX_BASE_FRAMES  100
//#define _8BIT

//#endif

#ifdef _8BIT
#define MAX_FRAMES      MAX_BASE_FRAMES*2
uint8_t frames[MAX_FRAMES][64];
#else
#define MAX_FRAMES      MAX_BASE_FRAMES
uint16_t frames[MAX_FRAMES][64];
#endif


// Frame variables
// Magnetic tile reading
int pixelOrder[] = {26, 27, 18, 19, 10, 11, 2, 3, 1, 0, 9, 8, 17, 16, 25, 24};
int subtileOrder[] = {0, 2, 1, 3};
int subtileOffset[] = {0, 4, 32, 36};
uint16_t frame[64];

int numFrames = 0;
int curFrame = 0;

#define MODE_IDLE          0
#define MODE_LIVE          1
#define MODE_HIGHSPEED1    2
#define MODE_HIGHSPEED2    3
#define MODE_HIGHSPEED3    4
#define MODE_HIGHSPEED4    5
#define MODE_PIXEL         6

int curMode = MODE_IDLE;



// Variables showing whether a given sensor is present and initialized
bool SENSOR_PRESENT_MLX90640;
bool SENSOR_PRESENT_SPS30;
bool SENSOR_PRESENT_SCD4X;
bool SENSOR_PRESENT_BME688;
bool SENSOR_PRESENT_MLX90393;

// Variables showing which sensor is being focused on right now
int current_focus_sensor = 0;

#define FOCUS_SENSOR_NONE             0
#define FOCUS_SENSOR_SPECTROMETER     1
#define FOCUS_SENSOR_MAGNETIC_TILE    2
#define FOCUS_SENSOR_MAGNETOMETER     3
// None of the rest require particularly high updates


/*
 *  Radiation Watch Type 5
 */

/*
int digipotSetting = 32;

void initDigipot() {
  pinMode(DIGIPOT_UD, OUTPUT);
  pinMode(DIGIPOT_CS, OUTPUT);

  digitalWrite(DIGIPOT_CS, 1);    // Inactive
  digitalWrite(DIGIPOT_UD, 0);    // N/A
}

void incrementDigipot(int val) {
  digitalWrite(DIGIPOT_CS, 1);    // Inactive
  delayMicroseconds(10);
  digitalWrite(DIGIPOT_UD, 1);    // Set to increment
  delayMicroseconds(10);

  digitalWrite(DIGIPOT_CS, 0);    // Active
  delayMicroseconds(10);

  for (int i=0; i<val; i++) {
    // Pulse to increment
    digitalWrite(DIGIPOT_UD, 0);    
    delayMicroseconds(10);
    digitalWrite(DIGIPOT_UD, 1);    
    delayMicroseconds(10);
  }

  digitalWrite(DIGIPOT_CS, 1);    // Inactive  
  delayMicroseconds(10);
}

void decrementDigipot(int val) {
  digitalWrite(DIGIPOT_CS, 1);    // Inactive
  delayMicroseconds(10);
  digitalWrite(DIGIPOT_UD, 0);    // Set to decrement
  delayMicroseconds(10);

  digitalWrite(DIGIPOT_CS, 0);    // Active
  delayMicroseconds(10);

  for (int i=0; i<val; i++) {
    // Pulse to decrement
    digitalWrite(DIGIPOT_UD, 1);    
    delayMicroseconds(10);
    digitalWrite(DIGIPOT_UD, 0);    
    delayMicroseconds(10);
  }

  digitalWrite(DIGIPOT_CS, 1);    // Inactive  
  delayMicroseconds(10);
}


void setDigipot(int num) {
  int delta = digipotSetting - num;
  if (delta > 0) {
    incrementDigipot(delta);
  } 
  if (delta < 0) {
    decrementDigipot(-delta);
  }
  digipotSetting += delta;
}

void setDigipotAbsolute(int num) {
  incrementDigipot(64);
  decrementDigipot(64 - num);
  //digipotSetting = 32;

  //setDigipot(num);
}
*/


/*
 *  Magnetic Imaging Tile
 */
/*
   Analog Read
*/
int readMagnetometer() {
  //return 0;
  //return analogRead(PIN_ANALOG);
  return readInternalADC();
  //return readAD7940();
  //return read_ad7940();
}

// Take one measurement form the internal ADC
int readInternalADC() {
  int numSamples = 2;
  float sum = 0.0f;
  for (int i = 0; i < numSamples; i++) {
    int sensorValue = analogRead(PIN_ANALOG);
    sum += sensorValue;
  }
  sum /= numSamples;

  //return sensorValue;
  return int(floor(sum));
}


// Take one measurement from an external AD7940 14-bit ADC (SPI)
/*
uint16_t readAD7940() {
  uint16_t value = 0;
  //uint16_t delay_time = 2;

  // Idle
  digitalWrite(AD7940_SPI_CS, HIGH);
  digitalWrite(AD7940_SPI_CLK, HIGH);

  // Enable
  digitalWrite(AD7940_SPI_CS, LOW);

  // Read 16 bits
  for (int i = 0; i < 16; i++) {
    char bit = digitalRead(AD7940_SPI_MISO);
    digitalWrite(AD7940_SPI_CLK, LOW);
    //    delayMicroseconds(delay_time);

    value = value << 1;
    value = value + (bit & 0x01);
    digitalWrite(AD7940_SPI_CLK, HIGH);
    //    delayMicroseconds(delay_time);
  }
  // Disable
  digitalWrite(AD7940_SPI_CS, HIGH);
  //  delayMicroseconds(delay_time);

  return value;
}
*/

/*
   Magnetic Sensors
*/
void clearCounter() {
  digitalWrite(PIN_CLR, 0);
  delayMicroseconds(2);     // Hold the clear pulse long enough for the 74HC590A to register it
  digitalWrite(PIN_CLR, 1);
  delayMicroseconds(2);     // Recovery time before the first clock edge
}

void incrementCounter() {
  digitalWrite(PIN_CLK, 1);
  delayMicroseconds(2);     // Hold the clock pulse long enough for the 74HC590A to register it
  digitalWrite(PIN_CLK, 0);
  delayMicroseconds(2);     // Let the counter/mux settle before the next ADC read
}

/*
   Capture one frame from imaging array
*/
void readTileFrame() {

  clearCounter();
  incrementCounter();

  for (int curSubtileIdx = 0; curSubtileIdx < 4; curSubtileIdx++) {
    for (int curIdx = 0; curIdx < 16; curIdx++) {
      // Read value
      int value = readMagnetometer();

      //terminal.println(value);
      //delay(10);

      // Store value in correct frame location
      int frameOffset = pixelOrder[curIdx] + subtileOffset[subtileOrder[curSubtileIdx]];
      //terminal.println(frameOffset);
      //delay(25);
      frame[frameOffset] = value;

      // Increment to next pixel
      incrementCounter();
    }
  }
}

// Display current frame on serial console
void displayCurrentFrame() {
  // Display frame
  Serial.println ("\nCurrent Magnetic Tile Frame");
  int idx = 0;
  for (int i = 0; i < 8; i++) {
    for (int j = 0; j < 8; j++) {
      //terminal.print( frame[idx] );
      //terminal.print( " " );
      Serial.print( frame[idx] );
      Serial.print(" ");
      idx += 1;
    }
    Serial.println("");
  }
  Serial.println("*");
}


void displayCurrentFrameJSON(Stream &port) {
  int idx = 0;
  const int error_state = 0;  // Currently doesn't detect any error states

  // Begin top-level object
  port.print(F("{\"sensor\":\"magnetic_tile\",\"payload\":{"));

  // "frame" array
  port.print(F("\"frame\":["));
  for (int row = 0; row < 8; row++) {
    port.print(F("["));
    for (int col = 0; col < 8; col++) {
      port.print(frame[idx]);
      if (col < 7) port.print(F(","));
      idx++;
    }
    port.print(F("]"));
    if (row < 7) port.print(F(","));
  }
  port.print(F("],"));

  // "timestamp" field
  port.print(F("\"timestamp\":"));
  port.print(millis());       // TODO: Should be updated by the read function
  port.print(F(","));

  // "error_state" field
  port.print(F("\"error_state\":"));
  port.print(error_state);

  // Close payload and top-level object
  port.print(F("}}"));
  port.println();
}



// Record MAX_FRAMES, as fast as possible
void recordHighSpeedFrames(int frameDelayTime) {
  long startTime = millis();

  for (int curFrame = 0; curFrame < MAX_FRAMES; curFrame++) {
    // Read one frame
    readTileFrame();

    // Store frame
#ifdef _8BIT
    for (int a = 0; a < 64; a++) {
      frames[curFrame][a] = frame[a] >> 2;
    }
#else
    for (int a = 0; a < 64; a++) {
      frames[curFrame][a] = frame[a];
    }
#endif

    if (frameDelayTime > 0) {
      delay(frameDelayTime);
    }
  }

  long endTime = millis();
  Serial.print("Framerate: ");
  Serial.println((float)MAX_FRAMES / ((float)(endTime - startTime) / 1000.0f));
}

// Playback the high speed frames stored
void playbackHighSpeedFrames() {

  for (int curFrame = 0; curFrame < MAX_FRAMES; curFrame++) {
    // Display frame
    //    terminal.print ("\nFrame ");
    //    terminal.println (curFrame);

    int idx = 0;
    for (int i = 0; i < 8; i++) {
      for (int j = 0; j < 8; j++) {
        Serial.print( frames[curFrame][idx] );
        Serial.print( " " );
        idx += 1;
      }
      Serial.println("");
    }
    Serial.println("*");
    delay(50);
  }
}




/*
 *  Sensors
 */ 
/*
void readMLX90640() {

  if (mlx.getFrame(mlx90640_frame) != 0) {
    Serial.println("Failed");
    return;
  }
  Serial.println("===================================");
  Serial.print("Ambient temperature = ");
  Serial.print(mlx.getTa(false)); // false = no new frame capture
  Serial.println(" degC");
  Serial.println();
  Serial.println();
  for (uint8_t h=0; h<24; h++) {
    for (uint8_t w=0; w<32; w++) {
      float t = mlx90640_frame[h*32 + w];
#ifdef PRINT_TEMPERATURES
      Serial.print(t, 0);
      Serial.print(", ");
#endif
#ifdef PRINT_ASCIIART
      char c = '&';
      if (t < 20) c = ' ';
      else if (t < 23) c = '.';
      else if (t < 25) c = '-';
      else if (t < 27) c = '*';
      else if (t < 29) c = '+';
      else if (t < 31) c = 'x';
      else if (t < 33) c = '%';
      else if (t < 35) c = '#';
      else if (t < 37) c = 'X';
      Serial.print(c);
#endif
    }
    Serial.println();
  }

}
*/


void readSPS30() {
  sensorSPS30.read_sps30();
  sensorSPS30.exportJSON(Serial);
}



/*
void readSCD4x() {

  if (sensorSCD4x.readMeasurement()) {
    Serial.println();

    Serial.print(F("CO2(ppm):"));
    Serial.print(sensorSCD4x.getCO2());

    Serial.print(F("\tTemperature(C):"));
    Serial.print(sensorSCD4x.getTemperature(), 1);

    Serial.print(F("\tHumidity(%RH):"));
    Serial.print(sensorSCD4x.getHumidity(), 1);

    Serial.println();
  } else {
    Serial.println("SCD4x reading not available.");
  }

}
*/

void readSCD4x(Stream &port) {
  int scd4x_error_state = 0;

  if (!sensorSCD4x.readMeasurement()) {
    scd4x_error_state = 1;
  }

  // Begin top‐level object
  port.print(F("{\"sensor\":\"scd4x\",\"payload\":"));

  // Begin payload object
  port.print(F("{"));

  if (scd4x_error_state == 0) {
    port.print(F("\"atmospheric\":{"));
    port.print(F("\"co2_ppm\":"));           port.print(sensorSCD4x.getCO2());         port.print(F(","));
    port.print(F("\"temp_c\":"));            port.print(sensorSCD4x.getTemperature(), 1); port.print(F(","));
    port.print(F("\"humidity_rh_pct\":"));   port.print(sensorSCD4x.getHumidity(), 1);
    port.print(F("},"));
  }

  // “timestamp” field
  port.print(F("\"timestamp\":"));
  port.print(millis());
  port.print(F(","));

  // error_state field
  port.print(F("\"error_state\":"));
  port.print(scd4x_error_state);

  // Close payload and top‐level
  port.print(F("}}"));
  port.println();
}



void readBME688(Stream &port) {  
  int bme688_error_state = 0;
  if (! bme.performReading()) {
    //Serial.println("Failed to perform reading :(");
    bme688_error_state = 1;    
  }

  /*
  Serial.print("Temperature = ");
  Serial.print(bme.temperature);
  Serial.println(" *C");

  Serial.print("Pressure = ");
  Serial.print(bme.pressure / 100.0);
  Serial.println(" hPa");

  Serial.print("Humidity = ");
  Serial.print(bme.humidity);
  Serial.println(" %");

  Serial.print("Gas = ");
  Serial.print(bme.gas_resistance / 1000.0);
  Serial.println(" KOhms");

  Serial.print("Approx. Altitude = ");
  Serial.print(bme.readAltitude(SEALEVELPRESSURE_HPA));
  Serial.println(" m");

  Serial.println();
  */

  // Begin top‐level object
  port.print(F("{\"sensor\":\"bme688\",\"payload\":"));

  // Begin payload object
  port.print(F("{"));

  if (bme688_error_state == 0) {
    // “mass” object
    port.print(F("\"magnetic\":{"));
    port.print(F("\"temp_c\":"));                 port.print(bme.temperature);        port.print(F(","));
    port.print(F("\"pressure_hpa\":"));           port.print(bme.pressure / 100.0);   port.print(F(","));
    port.print(F("\"gas_resistance_kohm\":"));    port.print(bme.gas_resistance / 1000.0);   port.print(F(","));
    port.print(F("\"altitude_m\":"));             port.print(bme.readAltitude(SEALEVELPRESSURE_HPA));
    port.print(F("},"));
  }

  // “timestamp” field
  port.print(F("\"timestamp\":"));
  port.print(millis());
  port.print(F(","));

  // error_state field
  port.print(F("\"error_state\":"));
  port.print(bme688_error_state);

  // Close payload and top‐level
  port.print(F("}}"));
  port.println();

}



void readMLX90393(Stream &port) {
  float x, y, z;
  int mag_error_state = 0;

  // get X Y and Z data at once
  if (!mlx90393.readData(&x, &y, &z)) {
      //Serial.println("MLX90393: Unable to read XYZ data from the sensor.");
      mag_error_state = 1;      
  }

  // Begin top‐level object
  port.print(F("{\"sensor\":\"mlx90393\",\"payload\":"));

  // Begin payload object
  port.print(F("{"));

  if (mag_error_state == 0) {
    // “mass” object
    port.print(F("\"magnetic\":{"));
    port.print(F("\"x_ut\":"));   port.print(x);   port.print(F(","));
    port.print(F("\"y_ut\":"));   port.print(y);   port.print(F(","));
    port.print(F("\"z_ut\":"));   port.print(z); 
    port.print(F("},"));
  }

  // “timestamp” field
  port.print(F("\"timestamp\":"));
  port.print(millis());
  port.print(F(","));

  // error_state field
  port.print(F("\"error_state\":"));
  port.print(mag_error_state);

  // Close payload and top‐level
  port.print(F("}}"));
  port.println();


}



/*
 * Setup/Main
 */ 

void setup() {
  // put your setup code here, to run once:
  
  // Serial debug console:
  Serial.begin(115200);
  Serial.println("Initializing...");
  delay(500);

  // Turn on the 3.3V regulator
  pinMode(PIN_3V_ENABLE, OUTPUT);
  digitalWrite(PIN_3V_ENABLE, HIGH);    // Enable regulator
  delay(500);

/*
  // Turn on the 5V regulator
  pinMode(PIN_5V_ENABLE, OUTPUT);
  digitalWrite(PIN_5V_ENABLE, HIGH);    // Enable 5V regulator
  delay(500);
*/

  Wire.begin();

  // TF Mini Plus initialization (Serial1)
  //Serial1.begin(115200);

/*
  // MLX90640 Thermopile Array initialization
  SENSOR_PRESENT_MLX90640 = false;
  if (!mlx.begin(MLX90640_I2CADDR_DEFAULT, &Wire)) {    
    Serial.println("MLX90640 not found!");
    SENSOR_PRESENT_MLX90640 = false;    
  } else {
    Serial.println("MLX90640 found!");
    SENSOR_PRESENT_MLX90640 = true;    
  }  

  mlx.setMode(MLX90640_CHESS);              // Set to Chess vs Interleave mode
  mlx.setResolution(MLX90640_ADC_18BIT);    // Set resolution
  //mlx.setResolution(MLX90640_ADC_16BIT);    // Set resolution
  mlx.setRefreshRate(MLX90640_2_HZ);        // Set refresh rate
  //mlx.setRefreshRate(MLX90640_4_HZ);        // Set refresh rate
*/


/*
  // Sensiron SPS30 Air Particle Detector
  SENSOR_PRESENT_SPS30 = false;
  sensirion_i2c_init();  
  for (int i=0; i<10; i++) {
    if (sps30_probe() != 0) {                
      Serial.print("SPS30 sensor probing failed\n");
      SENSOR_PRESENT_SPS30 = false;
      delay(250);      
    } else {
      Serial.println("SPS30 sensor found!");
      SENSOR_PRESENT_SPS30 = true;
      break;
    }
  }

  int16_t ret;
  uint8_t auto_clean_days = 4;
  uint32_t auto_clean;
  ret = sps30_set_fan_auto_cleaning_interval_days(auto_clean_days);

  if (ret) {
    Serial.print("error setting the auto-clean interval: ");
    Serial.println(ret);
  }

  ret = sps30_start_measurement();
  if (ret < 0) {
    Serial.print("error starting measurement\n");
  }
*/

  // Initialize the spectrometer
  Serial.println("Initializing Hamamatsu Spectrometer...");
  sensorSpec.begin();


  // SPS30 (UART driver)
  sensorSPS30.begin();


  // SCD4x CO2 sensor
  SENSOR_PRESENT_SCD4X = false;
  if (sensorSCD4x.begin() == false) {    
    Serial.println("SCD4x not detected!");    
    SENSOR_PRESENT_SCD4X = false;
  } else {
    Serial.println("SCD4x detected!");    
    SENSOR_PRESENT_SCD4X = true;
  }

  // BME688 Sensor
  if (!bme.begin(0x76)) {
    Serial.println("BME688 not found!");
    SENSOR_PRESENT_BME688 = false;
  } else {
    Serial.println("BME688 found!");
    SENSOR_PRESENT_BME688 = true;
  }

  // Set up oversampling and filter initialization
  if (SENSOR_PRESENT_BME688) {
    bme.setTemperatureOversampling(BME680_OS_8X);
    bme.setHumidityOversampling(BME680_OS_2X);
    bme.setPressureOversampling(BME680_OS_4X);
    bme.setIIRFilterSize(BME680_FILTER_SIZE_3);
    bme.setGasHeater(320, 150); // 320*C for 150 ms
  }

  // MLX90393 Magnetometer
  if (!mlx90393.begin_I2C()) {          // hardware I2C mode, can pass in address & alt Wire  
    Serial.println("MLX90393 not found!");
    SENSOR_PRESENT_MLX90393 = false;    
  } else {
    Serial.println("MLX90393 found!");
    SENSOR_PRESENT_MLX90393 = true;

    // Set gain
    mlx90393.setGain(MLX90393_GAIN_1X);
    // Set resolution, per axis. Aim for sensitivity of ~0.3 for all axes.
    mlx90393.setResolution(MLX90393_X, MLX90393_RES_17);
    mlx90393.setResolution(MLX90393_Y, MLX90393_RES_17);
    mlx90393.setResolution(MLX90393_Z, MLX90393_RES_16);

    // Set oversampling
    mlx90393.setOversampling(MLX90393_OSR_3);

    // Set digital filtering
    mlx90393.setFilter(MLX90393_FILTER_5);

  }

/*
  Serial.print("Initializing Radiation Watch Type 5...");
  // Radiation Watch Type 5
  // Initialize the digipot
  initDigipot();
  delay(10);
  //setDigipot(10);
  setDigipotAbsolute(55);
  delay(10);
*/

  // Initialize radiation sensor
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
void loop() {
  // put your main code here, to run repeatedly:

  // Read characters to select the sensor mode
  while (Serial.available() > 0) {
    char c = (char)Serial.read();

    if (c == 's') {
      current_focus_sensor = FOCUS_SENSOR_SPECTROMETER;
    } else if (c == 'm') {
      current_focus_sensor = FOCUS_SENSOR_MAGNETIC_TILE;
    } else if (c == 'n') {
      current_focus_sensor = FOCUS_SENSOR_MAGNETOMETER;
    } else if (isAlphaNumeric(c)) {
      current_focus_sensor = FOCUS_SENSOR_NONE;
    }
  }

  // Read TF Mini Plus distance
  /*
  int distance = 0;
  int strength = 0;
  bool success_tfmini = getTFminiPlusData(&distance, &strength);
  if (distance) {
    Serial.print(distance);
    Serial.print("cm\t");
    Serial.print("strength: ");
    Serial.println(strength);
  } else {
    Serial.println("No distance reading");
  }
  */

  // Read from MLX90640 thermopile array
  //readMLX90640();

  // Check the current focus sensor
  if (current_focus_sensor == FOCUS_SENSOR_SPECTROMETER) {
    // Hamamatsu Microspectrometer
    sensorSpec.readSpectrometer();
    sensorSpec.exportJSON(Serial);

  } else if (current_focus_sensor == FOCUS_SENSOR_MAGNETIC_TILE) {
    // Read from magnetic imaging tile
    readTileFrame();    
    displayCurrentFrameJSON(Serial);

    // Read from MLX90393 magnetic field sensor
    readMLX90393(Serial);

  } else if (current_focus_sensor == FOCUS_SENSOR_MAGNETOMETER) {
    // Read from MLX90393 magnetic field sensor
    readMLX90393(Serial);


  } else {
    // Focus: None/Everything
  

    // Read from SPS30 air particle sensor
    readSPS30();

    // Read from the SCD4x CO2 sensor
    readSCD4x(Serial);

    // Read from BME688 sensor
    readBME688(Serial);

    // Read from MLX90393 magnetic field sensor
    readMLX90393(Serial);

    // Read from magnetic imaging tile
    readTileFrame();
    //displayCurrentFrame();
    displayCurrentFrameJSON(Serial);

    // Hamamatsu Microspectrometer
    sensorSpec.readSpectrometer();
    sensorSpec.exportJSON(Serial);

  }
  
/*
  float cpm = sensorRadiation.calculateCPM();
  Serial.print ("CPM: ");  
  Serial.println(cpm, DEC);
  
  // Display pulse width histogram
  sensorRadiation.debugPrint();
  //sensorRadiation.exportJSON();
*/

  delay(1000);
}

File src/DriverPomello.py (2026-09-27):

# DriverPomello.py

import json
import time
import serial       # from pyserial



class PomelloRadiationSensor:
    def __init__(self, port:str="/dev/ttyACM0", baudrate:int=921600, timeout:float=2.0):
        self.port = port
        self.baudrate = baudrate
        self.timeout = timeout
        self.serial_port = None

        self.system_info = None
        self.config = None
        self.system_memory = None

    #
    #   Connect/Disconnect
    #

    # Open the serial connection
    def connect(self):
        try:
            self.serial_port = serial.Serial(self.port, self.baudrate, timeout=self.timeout)
            print(f"Connected to Pomello Radiation Sensor on {self.port} at {self.baudrate} baud.")
        except serial.SerialException as e:
            print(f"Error connecting to Pomello Radiation Sensor: {e}")
            self.serial_port = None

    # Close the serial connection
    def disconnect(self):
        if self.serial_port and self.serial_port.is_open:
            self.serial_port.close()
            print("Disconnected from Pomello Radiation Sensor.")


    #
    #   Start-up / initialization sequence
    #
    def initialize(self):
        # Connect to the device
        self.connect()

        # Wait for the device to be ready (e.g., after reboot)
        time.sleep(1)

        # Reboot
        #self.command_reboot()

        # Send these specific initialization commands:
        # z
        # 56411.816895
        # 6-122.66
        # t250
        # w-2024
        # x
        # Send the above initialization commands in sequence. Use the straight serial writes, not send_command.
        #self.deactivate_detector()   # z
        self.serial_port.write("z\n".encode('ascii'))   # z
        time.sleep(0.1)
        #self.send_command("56411.816895")   # 56411.816895
        self.serial_port.write("56411.816895\n".encode('ascii'))   # 56411.816895
        time.sleep(0.1)
        #self.send_command("6-122.66")   # 6-122.66
        self.serial_port.write("6-122.66\n".encode('ascii'))   # 6-122.66
        time.sleep(0.1)
        #self.send_command("t250")   # t250
        self.serial_port.write("t250\n".encode('ascii'))   # t250
        time.sleep(0.1)
        #self.send_command("w-2024")   # w-2024
        self.serial_port.write("w-2024\n".encode('ascii'))   # w-2024
        time.sleep(0.1)
        # self.send_command("x")   # x
        self.serial_port.write("x\n".encode('ascii'))   # x
        time.sleep(0.5)

        # Read any available information in the serial buffer to clear it out
        while (self.serial_port.in_waiting > 0):
            data = self.serial_port.read(self.serial_port.in_waiting).decode('ascii', errors='ignore')
            print(f"Initial serial data: {data}")
            time.sleep(0.1)


        # # Optionally, get system info or configuration to verify communication
        # self.system_info = self.command_get_system_info()
        # if (self.system_info is not None):
        #     print("System Information:")
        #     print(json.dumps(self.system_info, indent=4))
        # else:
        #     print("Failed to retrieve system information.")

        # # Configuration
        # self.config = self.command_get_config()
        # if (self.config is not None):
        #     print("Configuration:")
        #     print(json.dumps(self.config, indent=4))
        # else:
        #     print("Failed to retrieve configuration.")

        # # # Read the system memory
        # # self.system_memory = self.command_read_parameters()
        # # if (self.system_memory is not None):
        # #     print("System Memory:")
        # #     print(json.dumps(self.system_memory, indent=4))
        # # else:
        # #     print("Failed to read system memory.")

        # # Activate the detector
        # self.activate_detector()




    #
    #   Sending commands and receiving data (low-level)
    #

    def send_command(self, command:str, json_response:bool=False):
        if (self.serial_port is not None) and (self.serial_port.is_open == True):
            try:
                # Send the ASCII command
                self.serial_port.write(command.encode('ascii'))
                print(f"Sent command: {command}")
            except serial.SerialException as e:
                print(f"Error sending command: {e}")
        else:
            print("Serial port is not open. Cannot send command.")
            return None

        # Read the serial data until a newline character is received
        try:
            response = self.serial_port.readline().decode('ascii').strip()
            print(f"Received response: {response}")
            if (json_response == False):
                # Plain string response
                return response
            else:
                # Try to parse JSON response
                try:
                    json_data = json.loads(response)
                    return json_data
                except json.JSONDecodeError as e:
                    print(f"Error parsing JSON response: {e}")
                    return None

        except serial.SerialException as e:
            print(f"Error reading response: {e}")
            return None



    #
    #   Specific commands (high-level interface)
    #

    # System-level commands

    # Command: reboot the device
    # def command_reboot(self):
    #     response = self.send_command("e")
    #     # Wait for 2 seconds
    #     time.sleep(2)

    # Command: Get system information
    def command_get_system_info(self):
        response = self.send_command("s", json_response=True)
        return response

    # Command: Get configuration
    def command_get_config(self):
        response = self.send_command("c", json_response=True)
        return response

    def command_read_parameters(self):
        response = self.send_command("r", json_response=True)
        return response


    # Sensing commands
    def activate_detector(self):
        response = self.send_command("x", json_response=True)
        return response

    def deactivate_detector(self):
        response = self.send_command("z", json_response=True)
        return response


    def get_histogram(self):
        response = self.send_command("h", json_response=True)
        return response


    # Note: Starts a new counter after reading the current dose rate.
    def get_counts_per_minute(self):
        response = self.send_command("g", json_response=False)
        # Parse as a float
        try:
            cpm_value = float(response)
            return cpm_value
        except ValueError as e:
            print(f"Error parsing CPM value: {e}")
            return None
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

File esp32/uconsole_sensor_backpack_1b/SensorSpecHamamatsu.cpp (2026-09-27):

// SensorSpecHamamatsu.cpp
// An Arduino/Chipkit driver for the new Hamamatsu C12666MA Micro Spectrometer (released ~December 2013)
// Peter Jansen, September/2014. 
// -------------------------------------------------------------------------------------------------------------
// Nominally, the entire measurement process can be completed in a few lines of code:
//  SensorSpecHamamatsu sensor;
//  sensor.takeMeasurement();
//  sensor.debugPrint();
// There are also methods to control the integration (sample) time, the gain, and to convert the measurement
// into a SensorBuffer storage class.
// -------------------------------------------------------------------------------------------------------------

//#include <wprogram.h>
#include <Arduino.h>
#include "SensorSpecHamamatsu.h"

// Constructor
SensorSpecHamamatsu::SensorSpecHamamatsu() {
  // Initialize arrays
  for (int i=0; i<SPEC_CHANNELS; i++) {
    data[i] = 0;     
  }    
  timeSampled = 0;
}

// Destructor
SensorSpecHamamatsu::~SensorSpecHamamatsu() {
}
  
boolean SensorSpecHamamatsu::begin(){
  // Setup pins
  
  pinMode(SPEC_EOS, INPUT);
  pinMode(SPEC_GAIN, OUTPUT);
  pinMode(SPEC_ST, OUTPUT);
  pinMode(SPEC_CLK, OUTPUT);
  
  /*
  pinMode(SPEC_ANALOG_IN, INPUT);
  */
  
  // Default settings
  digitalWrite(SPEC_GAIN, HIGH);
  digitalWrite(SPEC_ST, HIGH);  
  digitalWrite(SPEC_CLK, HIGH); 
  
  setGain(0);
  setIntTime(100);
  
  return true;
}

void SensorSpecHamamatsu::setIntTime(uint16_t time) {
  // Set the integration (or sample collection) time, in milliseconds
  // 60ms might be about the shortest integration time with the current ADC timings
  intTime = time;
}

void SensorSpecHamamatsu::setGain(uint8_t highLow) {
  // Gain is either 0 (low gain) or 1 (high gain)
  gain = highLow;
  if (gain == 0) {
    digitalWrite(SPEC_GAIN, 0);
  } else {
    digitalWrite(SPEC_GAIN, 1);
  }
}
      
// Low-level communication 
uint16_t SensorSpecHamamatsu::readAD7940() {
  //TODO: Just read the ADC 
  uint16_t raw14 = 0;
  raw14 += analogRead(SPEC_ANALOG_IN);       // 0–4095
  raw14 += analogRead(SPEC_ANALOG_IN);       // 0–4095
  raw14 += analogRead(SPEC_ANALOG_IN);       // 0–4095
  raw14 += analogRead(SPEC_ANALOG_IN);       // 0–4095
  return raw14;
}

/*
void SensorSpecHamamatsu::readSpectrometer() {
  //uint16_t data = &data;
  int delay_time = 35;     // delay per half clock (in microseconds).  This ultimately conrols thesp integration time. 
  int idx = 0;
  int read_time = 35;      // Amount of time that the readAD7940() procedure takes (in microseconds)
  
  // Set the last time sampled
  timeSampled = millis();
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

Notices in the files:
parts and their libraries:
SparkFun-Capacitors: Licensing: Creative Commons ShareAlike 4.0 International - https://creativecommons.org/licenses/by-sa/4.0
